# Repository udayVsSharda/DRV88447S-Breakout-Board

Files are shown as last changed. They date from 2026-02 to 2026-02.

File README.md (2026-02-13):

# DRV88447S-Breakout-Board
A DRV8847 Breakout Board for driving Stepper Motors, Brushed DC Motors and Solenoids. The motor supply voltage can be between 2.7V to 18V. Digital control signals at 3.3V,  allows indirect control through I2C or direct control through 4 GPIO inputs to the Dual H-bridges. Along with the KiCAD files, I have also included manufacturing files for JLCPCB. The PCB was successfully manufactured and SMT assembled by JLCPCB in December 2025.
## Kicad Render
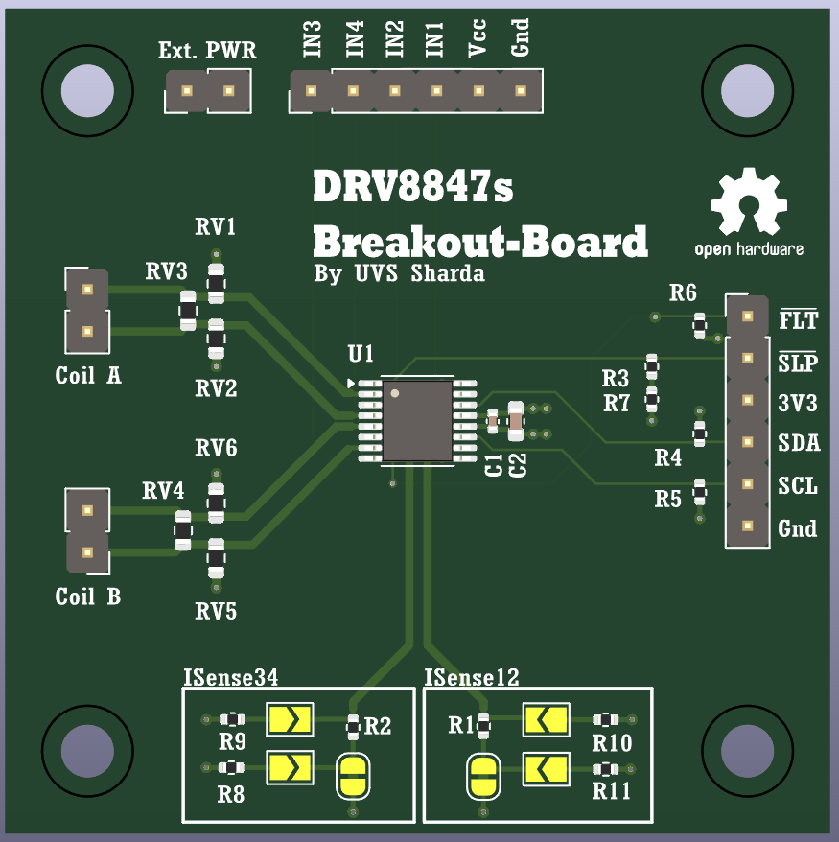
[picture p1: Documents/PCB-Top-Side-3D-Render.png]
3D Render

## Credit
[Uday Vivek Singh SHARDA](https://www.linkedin.com/in/uday-vivek-singh-sharda-988475122/)  
EENG2 P2029 ECAM LaSalle Lyon  
[KiCAD 8.0](https://www.kicad.org/)
## License
Hardware design files in this repository are licensed under the CERN-OHL-P-2.0 license.
See the LICENSE file for full terms.

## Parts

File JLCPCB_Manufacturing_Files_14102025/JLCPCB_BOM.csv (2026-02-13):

Designator | Comment | Footprint | LCSC Part Number
C1 | 0.1u | C_0402_1005Metric | C307331
C2 | 10u | C_0603_1608Metric | C344022
R1,R2,R8,R9,R10,R11 | 330m | R_0402_1005Metric | C1705212
R3,R6,R7 | 10k | R_0402_1005Metric | C25744
R4,R5 | 500 | R_0402_1005Metric | C25123
RV1,RV2,RV3,RV4,RV5,RV6 | RL0603A330K | R_0603_1608Metric | C2935569
U1 | DRV8847SPWR | TSSOP-16_4.4x5mm_P0.65mm | C701804

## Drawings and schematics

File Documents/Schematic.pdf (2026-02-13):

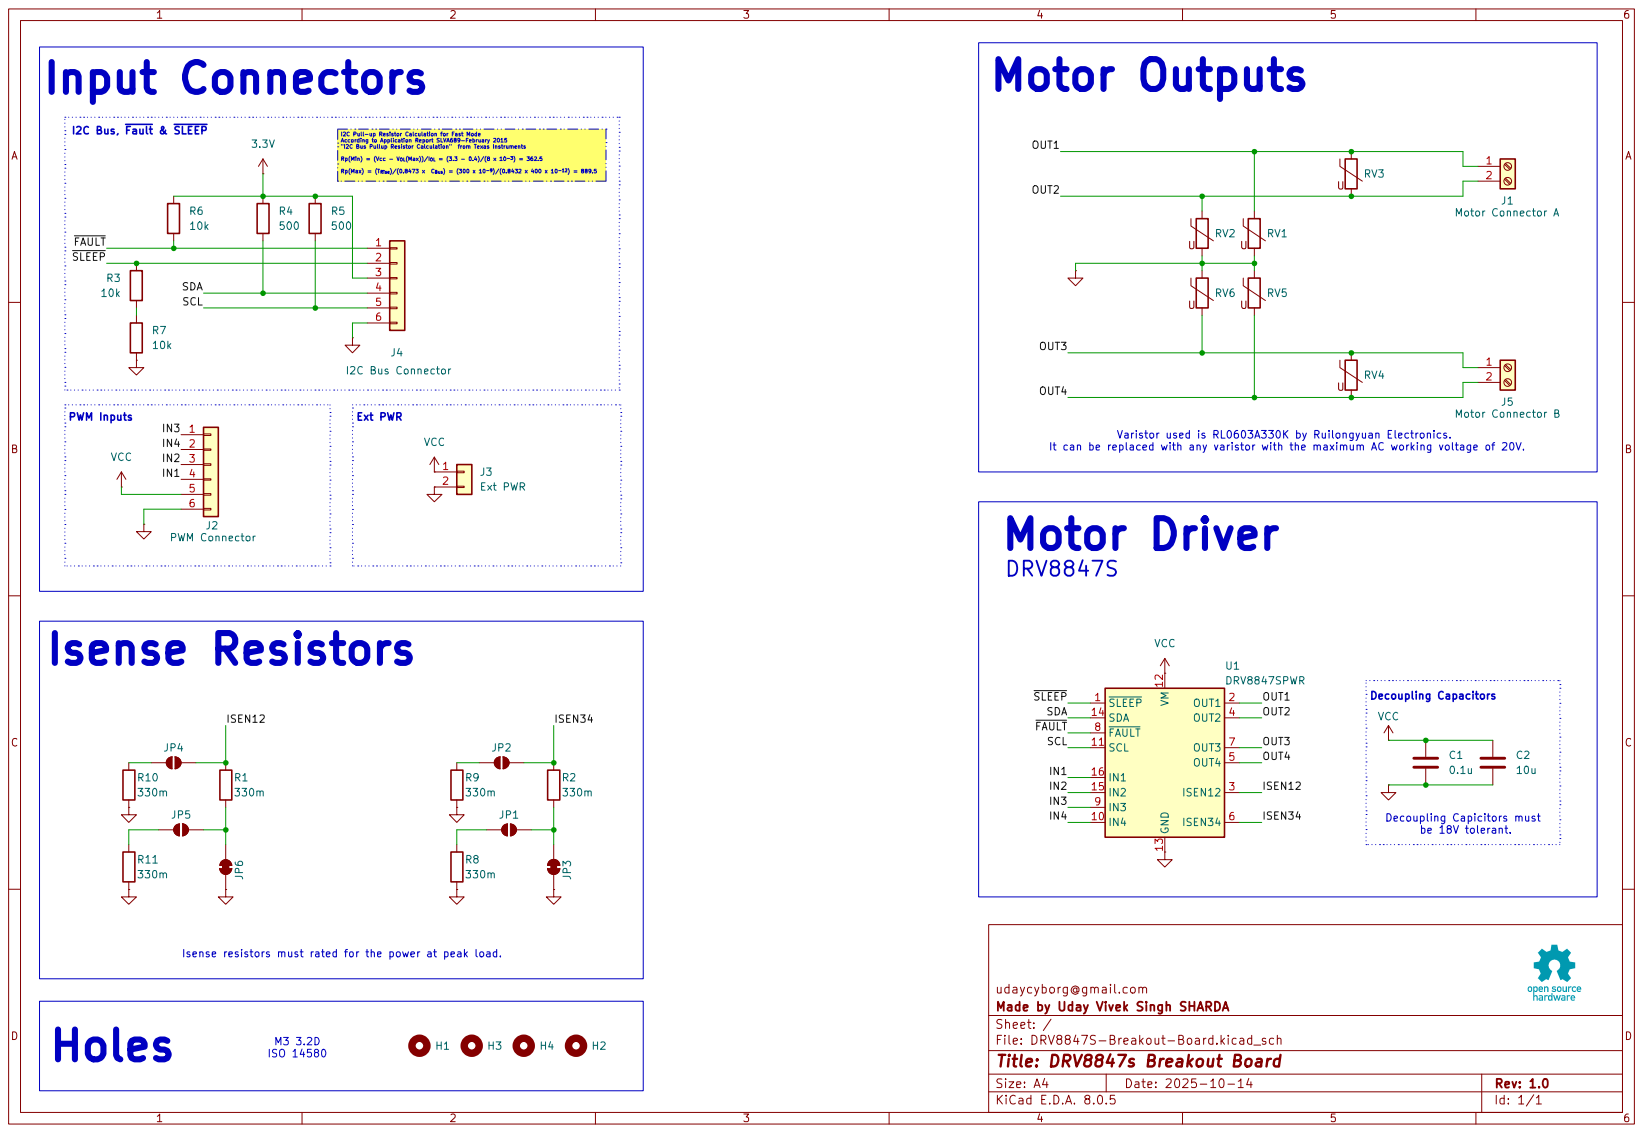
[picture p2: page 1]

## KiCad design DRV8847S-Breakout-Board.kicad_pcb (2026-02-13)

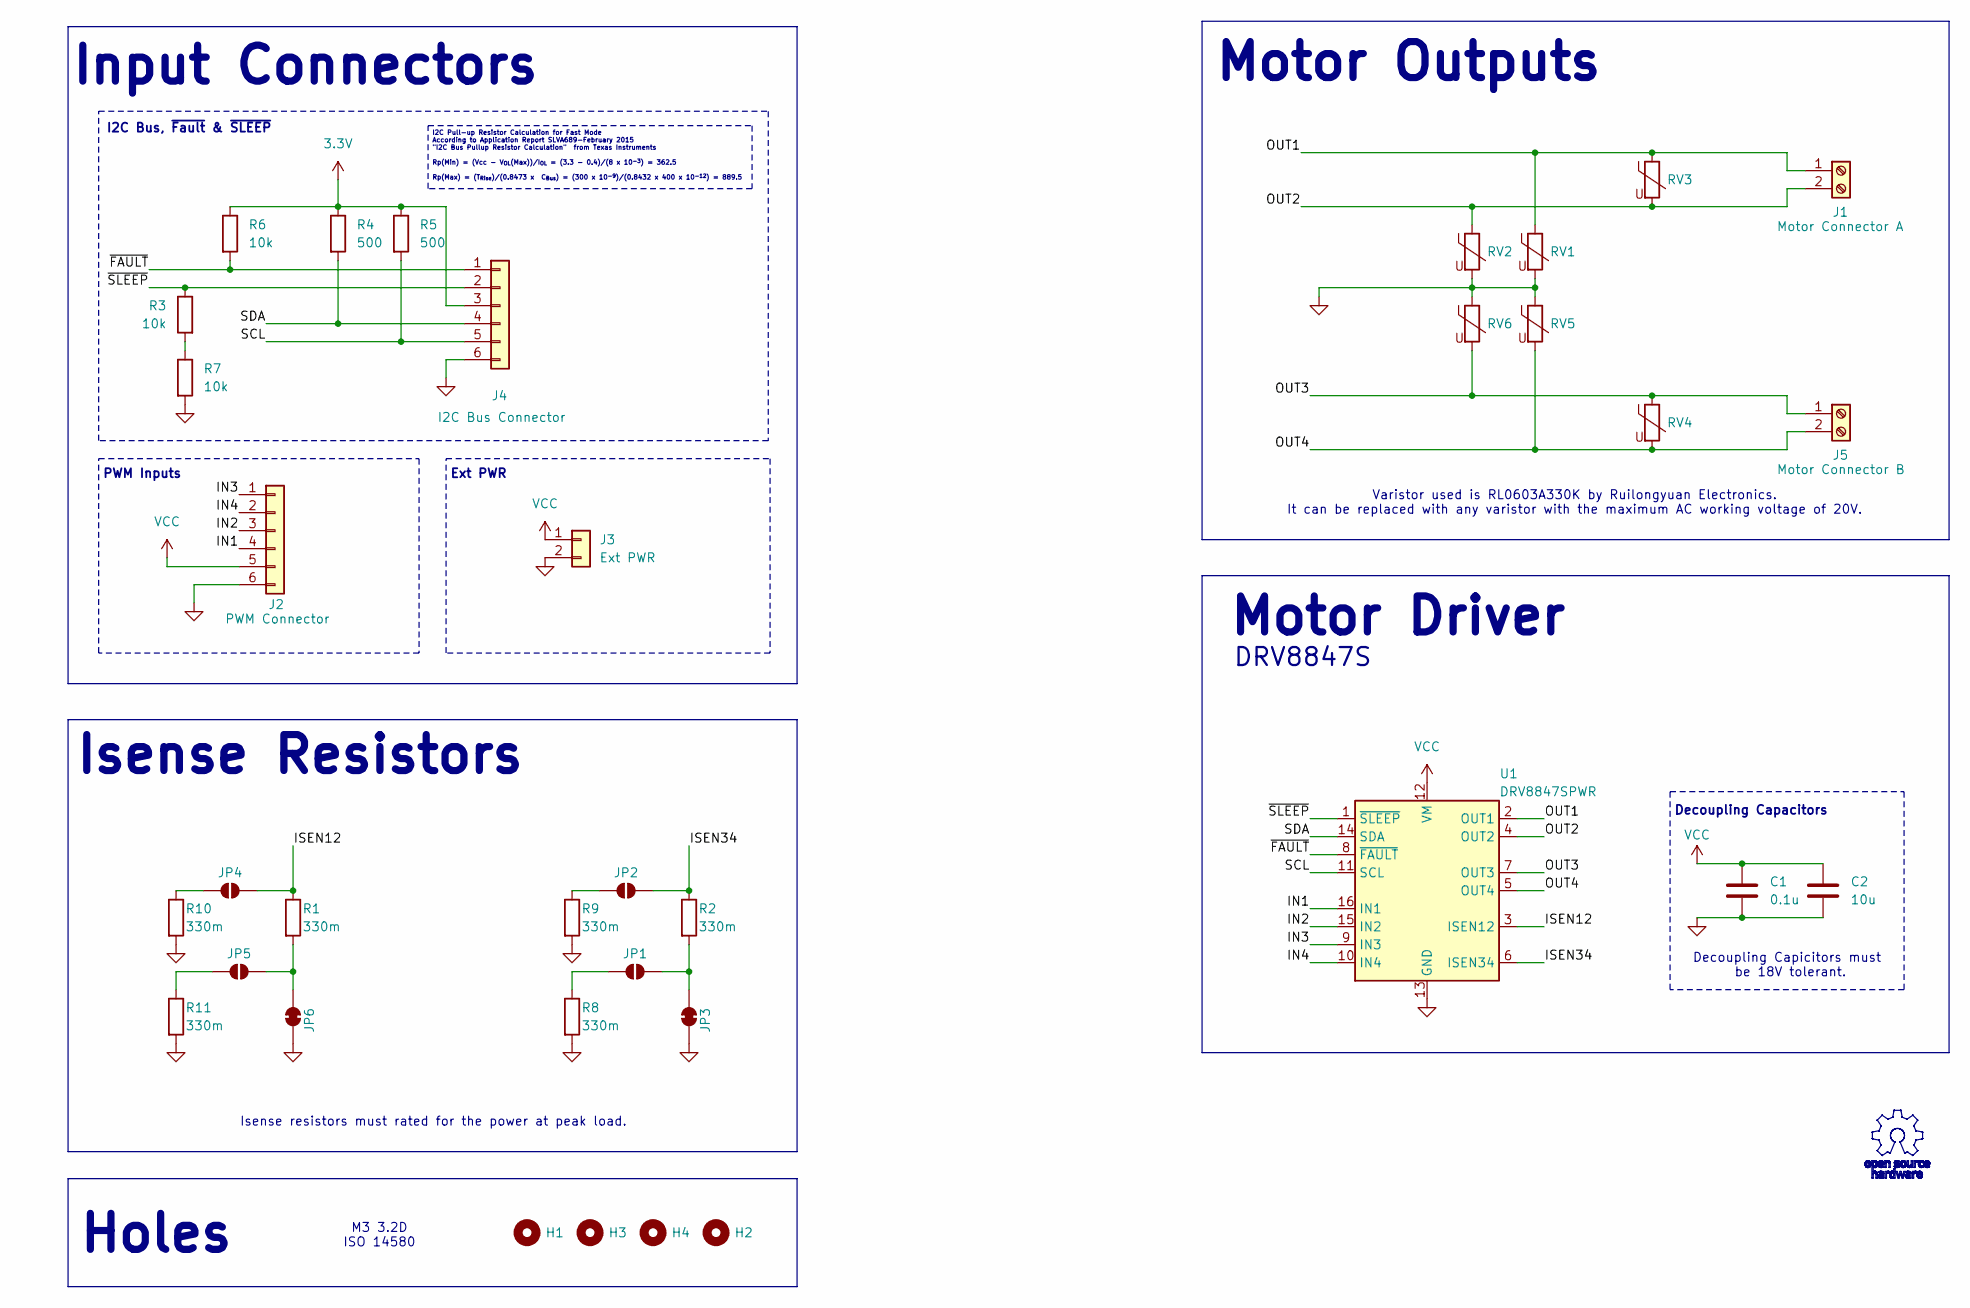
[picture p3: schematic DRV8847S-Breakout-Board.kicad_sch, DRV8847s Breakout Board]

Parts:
C1: 0.1u; C_0402_1005Metric
C2: 10u; C_0603_1608Metric
H1, H2, H3, H4: MountingHole; MountingHole_3.2mm_M3_ISO14580
J1: Motor Connector A; PinHeader_1x02_P2.54mm_Vertical
J2: PWM Connector; PinHeader_1x06_P2.54mm_Vertical
J3: Ext PWR; PinHeader_1x02_P2.54mm_Vertical
J4: I2C Bus Connector; PinHeader_1x06_P2.54mm_Vertical
J5: Motor Connector B; PinHeader_1x02_P2.54mm_Vertical
JP1, JP2, JP4, JP5: SolderJumper_2_Open; SolderJumper-2_P1.3mm_Open_TrianglePad1.0x1.5mm
JP3, JP6: SolderJumper_2_Bridged; SolderJumper-2_P1.3mm_Bridged_RoundedPad1.0x1.5mm
R1, R2, R8, R9, R10, R11: 330m; R_0402_1005Metric
R3, R6, R7: 10k; R_0402_1005Metric
R4, R5: 500; R_0402_1005Metric
RV1, RV2, RV3, RV4, RV5, RV6: RL0603A330K; R_0603_1608Metric
U1: DRV8847SPWR; TSSOP-16_4.4x5mm_P0.65mm

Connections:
3.3V: J4.3, R4.1, R5.1, R6.1
/IN1: J2.4, U1.16 (IN1)
/IN2: J2.3, U1.15 (IN2)
/IN3: J2.1, U1.9 (IN3)
/IN4: J2.2, U1.10 (IN4)
/ISEN12: JP4.2 (B), R1.1, U1.3 (ISEN12)
/ISEN34: JP2.2 (B), R2.1, U1.6 (ISEN34)
/OUT1: J1.1, RV1.1, RV3.1, U1.2 (OUT1)
/OUT2: J1.2, RV2.1, RV3.2, U1.4 (OUT2)
/OUT3: J5.1, RV4.1, RV6.2, U1.7 (OUT3)
/OUT4: J5.2, RV4.2, RV5.2, U1.5 (OUT4)
/SCL: J4.5, R5.2, U1.11 (SCL)
/SDA: J4.4, R4.2, U1.14 (SDA)
/~FAULT: J4.1, R6.2, U1.8 (~FAULT)
/~SLEEP: J4.2, R3.1, U1.1 (~SLEEP)
GND: C1.2, C2.2, J2.6, J3.2, J4.6, JP3.2 (B), JP6.2 (B), R7.2, R8.2, R9.2, R10.2, R11.2, RV1.2, RV2.2, RV5.1, RV6.1, U1.13 (GND)
unnamed: JP1.1 (A), R8.1
unnamed: JP1.2 (B), JP3.1 (A), R2.2
unnamed: JP2.1 (A), R9.1
unnamed: JP4.1 (A), R10.1
unnamed: JP5.1 (A), R11.1
unnamed: JP5.2 (B), JP6.1 (A), R1.2
unnamed: R3.2, R7.1
VCC: C1.1, C2.1, J2.5, J3.1, U1.12 (VM)

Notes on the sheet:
I2C Pull-up Resistor Calculation for Fast Mode According to Application Report SLVA689-February 2015 "I2C Bus Pullup Resistor Calculation" from Texas Instruments Rp(Min) = (Vcc - V_{OL}(Max))/I_{OL} = (3.3 - 0.4)/(8 x 10^{-3}) = 362.5 Rp(Max) = (T_{Rise})/(0.8473 x C_{Bus}) = (300 x 10^{-9})/(0.843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
I2C Bus, ~{Fault} & ~{SLEEP}
PWM Inputs
Varistor used is RL0603A330K by Ruilongyuan Electronics. It can be replaced with any varistor with the maximum AC working voltage of 20V.
Ext PWR
Isense resistors must rated for the power at peak load.
Motor Driver
Isense Resistors
Input Connectors
M3 3.2D ISO 14580
Holes
Decoupling Capacitors
Decoupling Capicitors must be 18V tolerant.
Motor Outputs
DRV8847S

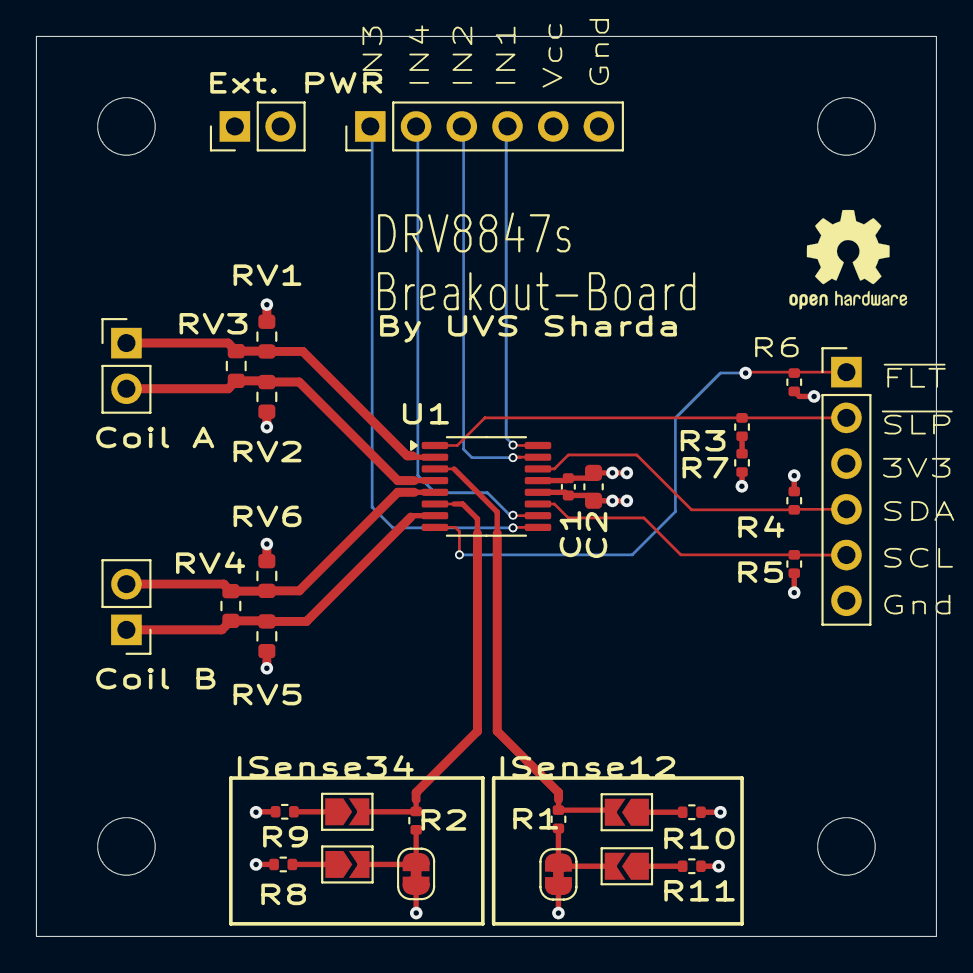
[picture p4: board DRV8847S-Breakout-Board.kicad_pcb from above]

Board: 4 copper layers, 50.0 x 50.0 mm, 35 parts (0 on the bottom side), 24 nets.
